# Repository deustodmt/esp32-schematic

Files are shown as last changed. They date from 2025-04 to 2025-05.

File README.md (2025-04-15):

# Proyecto PCB para Moto Eléctrica de Competición

Este repositorio documenta el diseño y desarrollo de una PCB para una moto eléctrica de competición. El objetivo principal es crear una placa personalizada basada en la ESP32-S3-DevKitC-1 que integre varios sensores y módulos esenciales para la recolección de datos, comunicación y navegación del vehículo.

---

## 📈 Estado actual del proyecto

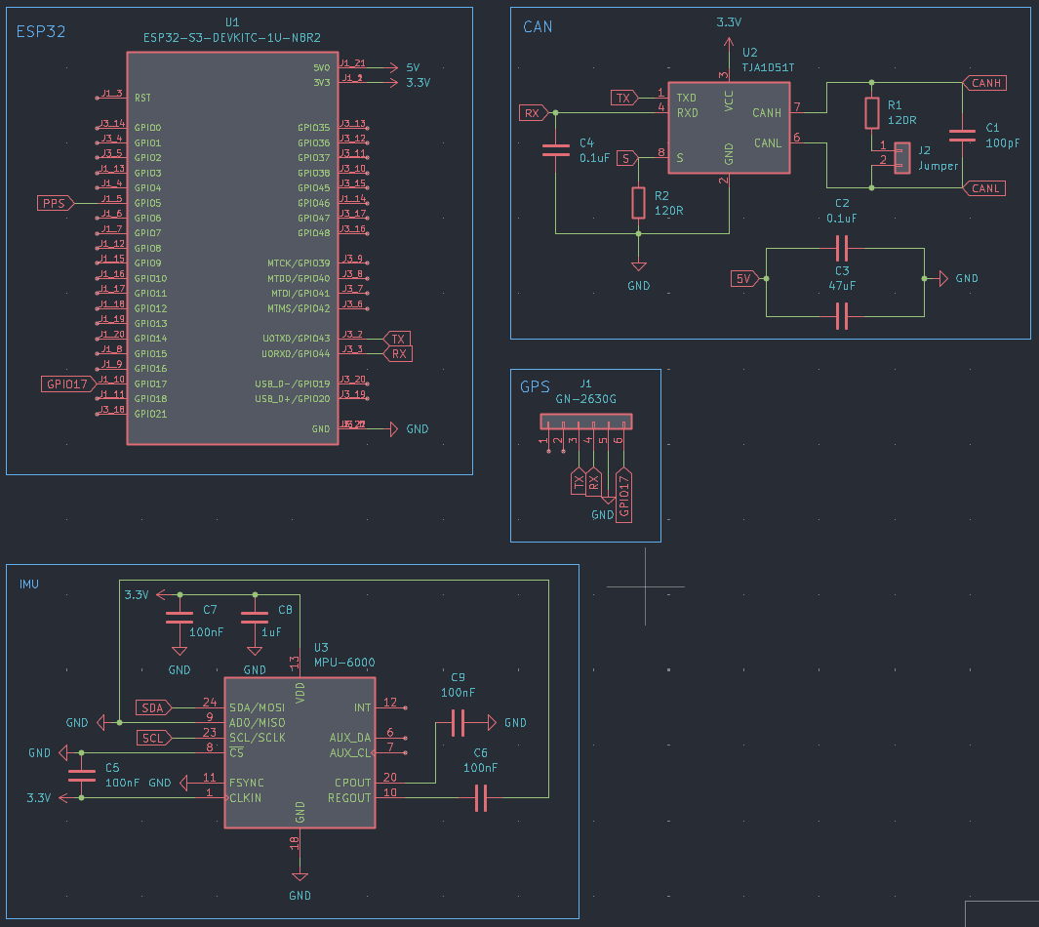
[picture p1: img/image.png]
schematic


---

## 🪤 Módulos incluidos en el diseño

### ESP32-S3-DevKitC-1
Microcontrolador principal encargado de recopilar datos de los sensores, procesarlos y transmitir información vía CAN o WiFi/Bluetooth. Este microcontrolador se elige por su versatilidad, potencia y conectividad.

### CAN (Controller Area Network)
Permite la comunicación robusta y rápida entre la ESP32 y otros controladores del sistema, como el BMS (Battery Management System) o la ECU (Electronic Control Unit). Se utiliza el transceptor TJA1051T para traducir las señales lógicas de la ESP32 al bus CAN.

### IMU (Unidad de Medición Inercial)
Usando el módulo MPU-6000, permite conocer la aceleración y rotación de la moto en tiempo real. Es fundamental para la telemetría y el análisis de dinámica del vehículo.

### GPS
El módulo GN-2630G proporciona la localización de la moto mediante señal satelital. Este dato es crucial para conocer la trayectoria y velocidad en pista.

### ENV (Sensor ambiental) *(Añadir cuando se incluya)*
Este módulo recogerá datos como temperatura, presión y humedad, los cuales podrían ser útiles para ajustar el rendimiento de la moto o estudiar las condiciones en pista.

---

## 📝 Diseño de la PCB

El diseño de la PCB ha sido elaborado buscando:
- **Minimizar interferencias** entre módulos sensibles como el GPS o la IMU.
- **Facilitar el ruteado** de las pistas, manteniendo las pistas de alimentación más anchas y las de señal bien definidas.
- **Disposición funcional** de los componentes, agrupando por función: comunicación, sensores, alimentación.
- **Posibilidad de depuración** y pruebas: se dejan pines de testeo accesibles.

Los principios seguidos incluyen buenas prácticas de colocación de condensadores de desacoplo, rutas cortas para señales críticas, y separación adecuada entre señales analógicas y digitales.

---

## ⚖️ Uso de KiCad

Para el diseño del proyecto se ha utilizado **KiCad**, una suite libre de diseño de PCB.

### Metodología de trabajo:
1. **Esquemático:** Creación del diagrama esquemático conectando todos los componentes.
2. **Asignación de huellas (footprints):** Asociación de cada componente con su huella física.
3. **Diseño de la PCB:** Colocación y ruteado de las pistas.
4. **Verificación DRC/ERC:** Comprobaciones de reglas eléctricas y de diseño.
5. **Exportación de archivos Gerber:** Preparación para fabricación.
6. **Renderizado 3D:** Visualización realista de la placa antes de su fabricación.

### Plugins útile:
- **KiCad-Diff:** Para ver cambios entre commits.
- **Interactive HTML BOM:** Genera una lista de materiales navegable visualmente.
- **SnapEDA / SamacSys Plugin:** Importación directa de modelos de componentes.

---

## 🚚 Fabricación de PCBs

Para la fabricación se recomienda:

- **JLCPCB**: https://jlcpcb.com/
  - Plataforma popular y asequible para fabricar placas PCB a partir de archivos Gerber.
- **LCSC**: https://lcsc.com/
  - Proveedor de componentes electrónicos que permite integración directa con JLCPCB para el montaje.
- **SnapMagic / SamacSys**: https://www.snapeda.com/
  - Herramienta para obtener símbolos, huellas y modelos 3D de componentes para integrarlos en KiCad.

---

## 📊 Conceptos básicos del diseño de PCBs

### Esquema de componentes (Schematic)
Representación lógica de cómo se conectan los componentes del circuito. No representa distancias ni posiciones físicas.

### Diseño de la PCB
Proceso de colocación física de los componentes y trazado de pistas que conectan los nodos definidos en el esquema.

### Renderizado 3D
Visualización tridimensional de la placa para comprobar posibles errores mecánicos y facilitar presentaciones.

### Archivos Gerber
Conjunto de archivos estándar que describen la geometría y capas de una placa PCB. Son enviados al fabricante para producir la placa.

---

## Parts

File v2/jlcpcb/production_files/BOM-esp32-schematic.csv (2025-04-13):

Comment | Designator | Footprint | LCSC | Quantity
TJA1051T | U2 | SOIC-8_3.9x4.9mm_P1.27mm |  | 1
GPS | J1 | PinHeader_1x06_P2.54mm_Vertical |  | 1
ESP32-S3-DEVKITC-1U-N8R2 | U1 | XCVR_ESP32-S3-DEVKITC-1U-N8R2 |  | 1
120R | R1 | R_1206_3216Metric |  | 1

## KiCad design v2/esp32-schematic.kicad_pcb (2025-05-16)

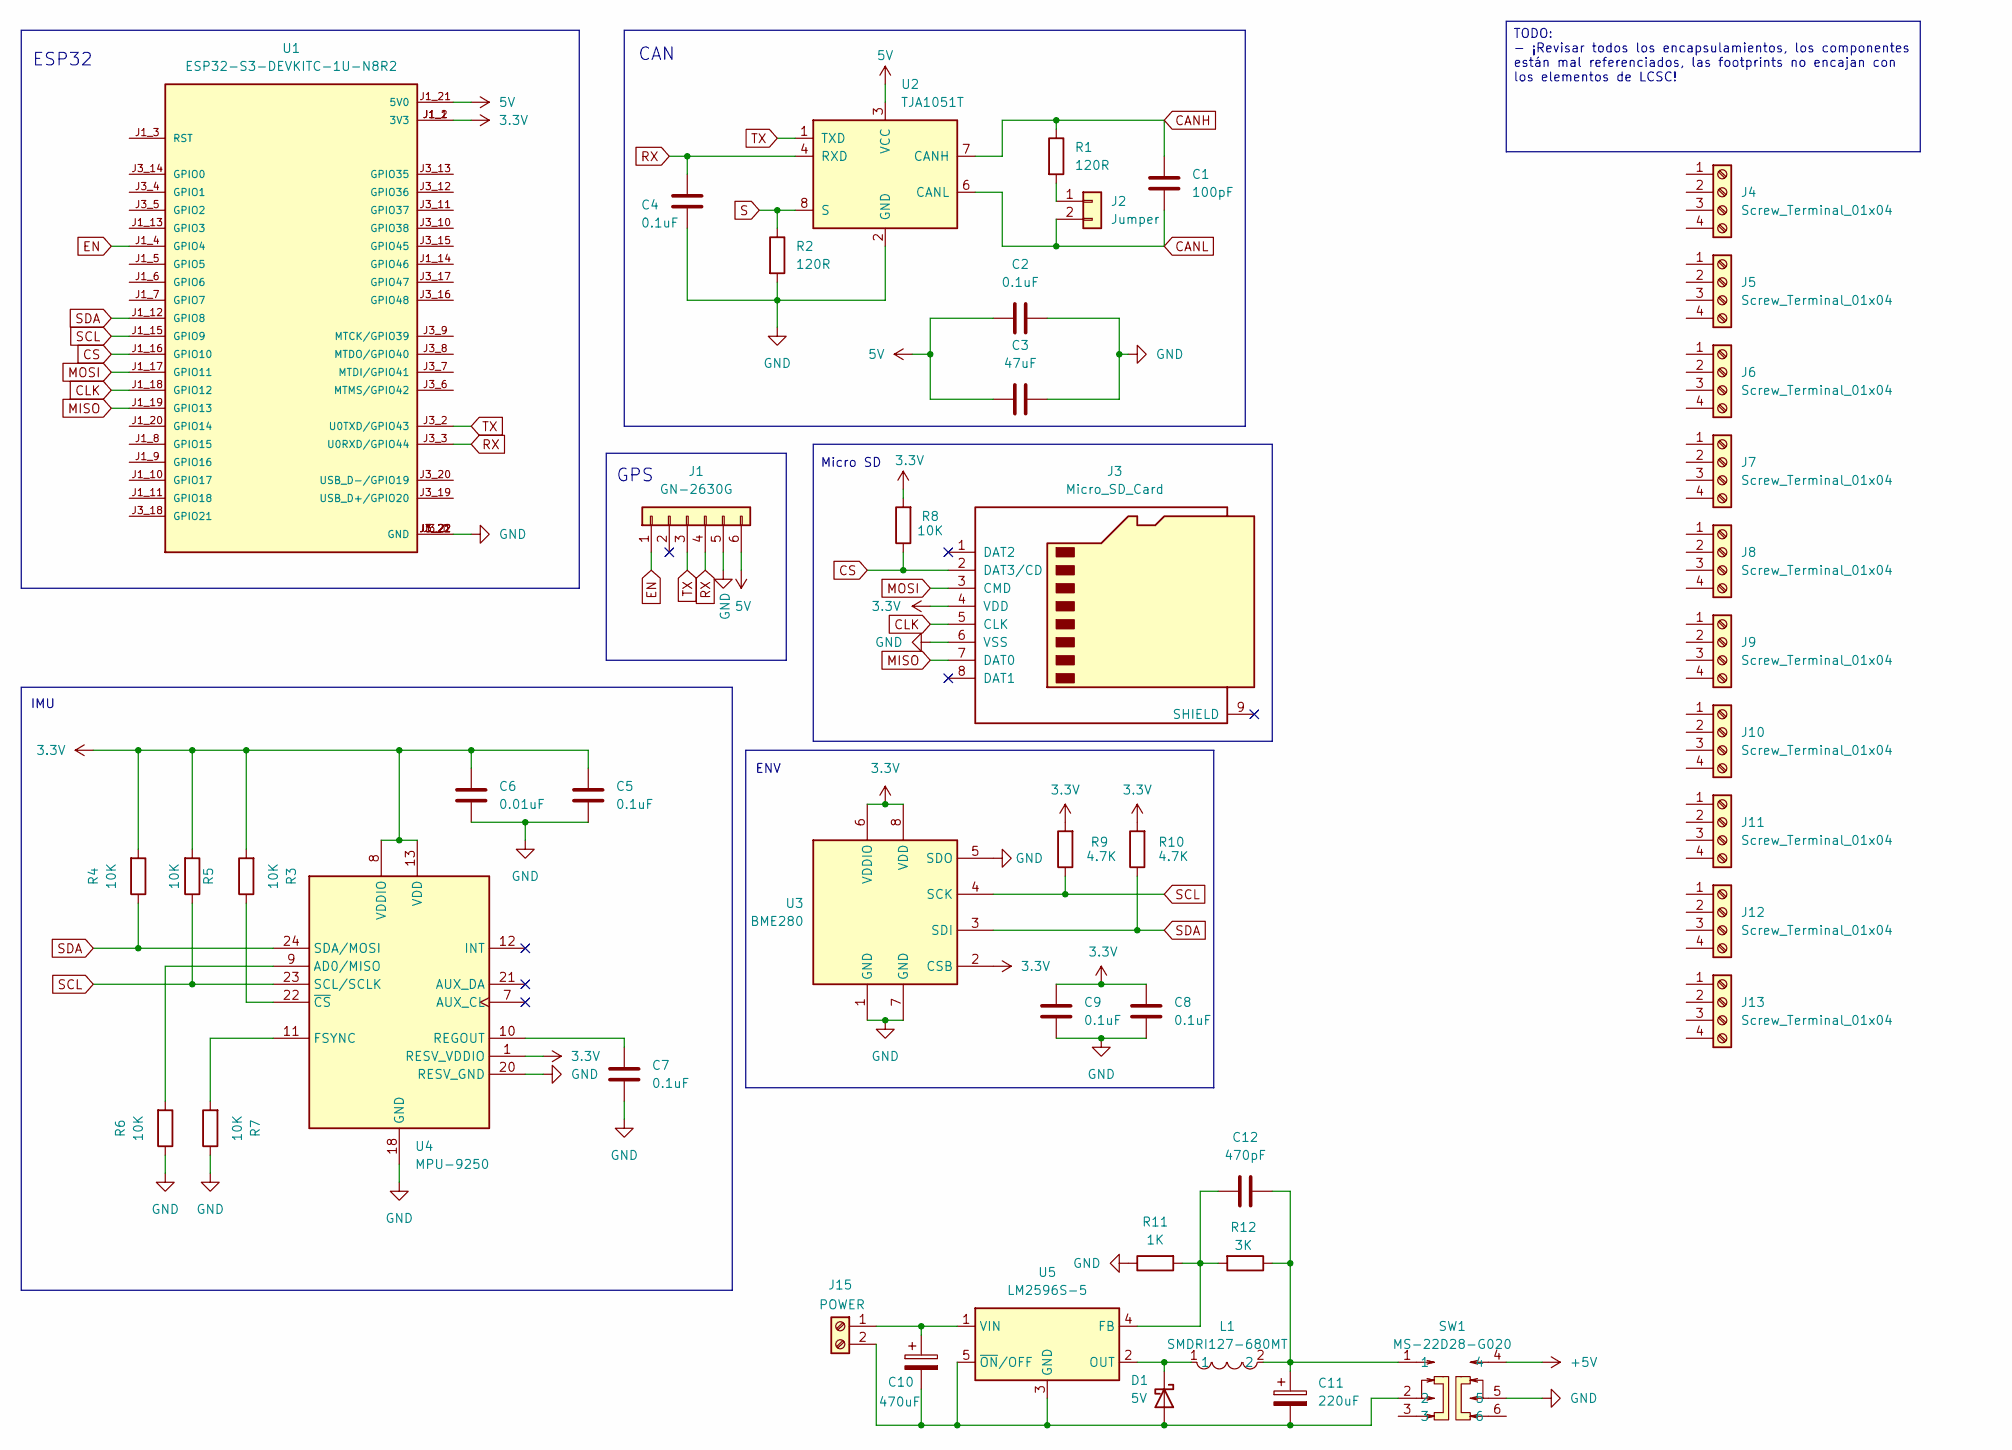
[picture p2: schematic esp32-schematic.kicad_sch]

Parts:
C1: 100pF; C_0805_2012Metric
C2, C4, C5, C7, C8, C9: 0.1uF; C_0805_2012Metric
C3: 47uF; C_0805_2012Metric
C6: 0.01uF; C_0805_2012Metric
C10: 470uF; CP_Radial_D10.0mm_P5.00mm
C11: 220uF; CP_Elec_10x10
C12: 470pF; C_0201_0603Metric
D1: 5V; D_SMA
J1: GN-2630G; PinHeader_1x06_P2.54mm_Vertical
J2: Jumper; PinHeader_1x02_P1.00mm_Vertical
J3: Micro_SD_Card; microSD_HC_Molex_104031-0811
J4, J5, J6, J7, J8, J9, J10, J11, J12, J13: Screw_Terminal_01x04; TerminalBlock_Phoenix_MKDS-1,5-4-5.08_1x04_P5.08mm_Horizont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
J15: POWER; TerminalBlock_Phoenix_PT-1,5-2-3.5-H_1x02_P3.50mm_Horizontal
L1: SMDRI127-680MT; IND-SMD_L12.3-W12.3_SMDRI127; LCSC Part C9907
R1, R2: 120R; R_1206_3216Metric
R3, R4, R5, R6, R7, R8: 10K; R_1206_3216Metric
R9, R10: 4.7K; R_1206_3216Metric
R11: 1K; R_0201_0603Metric
R12: 3K; R_Axial_DIN0411_L9.9mm_D3.6mm_P15.24mm_Horizontal
SW1: MS-22D28-G020; SW-SMD_MS-22D28-G020; LCSC Part C963205
U1: ESP32-S3-DEVKITC-1U-N8R2; XCVR_ESP32-S3-DEVKITC-1U-N8R2; PARTREV 5.3
U2: TJA1051T; SOIC-8_3.9x4.9mm_P1.27mm
U3: BME280; Bosch_LGA-8_2.5x2.5mm_P0.65mm_ClockwisePinNumbering
U4: MPU-9250; InvenSense_QFN-24_3x3mm_P0.4mm
U5: LM2596S-5; TO-263-5_TabPin3

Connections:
3.3V: C5.1, C6.1, C8.1, C9.1, J3.4 (VDD), R3.2, R4.2, R5.2, R8.2, R9.2, R10.2, U1.J1_1 (3V3), U1.J1_2 (3V3), U3.2 (CSB), U3.6 (VDDIO), U3.8 (VDD), U4.1 (RESV_VDDIO), U4.8 (VDDIO), U4.13 (VDD)
5V: C2.1, C3.1, J1.6, U1.J1_21 (5V0), U2.3 (VCC)
+5V: SW1.4
CANH: C1.1, R1.1, U2.7 (CANH)
CANL: C1.2, J2.2, U2.6 (CANL)
CLK: J3.5 (CLK), U1.J1_18 (GPIO12)
CS: J3.2 (DAT3/CD), R8.1, U1.J1_16 (GPIO10)
EN: J1.1, U1.J1_4 (GPIO4)
GND: C2.2, C3.2, C4.2, C5.2, C6.2, C7.2, C8.2, C9.2, J1.5, J3.6 (VSS), R2.2, R6.1, R7.1, R11.1, SW1.5, U1.J1_22 (GND), U1.J3_1 (GND), U1.J3_21 (GND), U1.J3_22 (GND), U2.2 (GND), U3.1 (GND), U3.5 (SDO), U3.7 (GND), U4.18 (GND), U4.20 (RESV_GND)
MISO: J3.7 (DAT0), U1.J1_19 (GPIO13)
MOSI: J3.3 (CMD), U1.J1_17 (GPIO11)
unnamed: C11.1, C12.2, L1.2, R12.1, SW1.1
unnamed: C10.2, C11.2, D1.2 (A), J15.2, SW1.2, U5.3 (GND), U5.5 (~ON/OFF)
unnamed: D1.1 (K), L1.1, U5.2 (OUT)
unnamed: J2.1, R1.2
unnamed: C10.1, J15.1, U5.1 (VIN)
unnamed: R6.2, U4.9 (AD0/MISO)
unnamed: R7.2, U4.11 (FSYNC)
unnamed: C7.1, U4.10 (REGOUT)
unnamed: R3.1, U4.22 (~CS)
unnamed: C12.1, R11.2, R12.2, U5.4 (FB)
RX: C4.1, J1.4, U1.J3_3 (U0RXD/GPIO44), U2.4 (RXD)
S: R2.1, U2.8 (S)
SCL: R5.1, R9.1, U1.J1_15 (GPIO9), U3.4 (SCK), U4.23 (SCL/SCLK)
SDA: R4.1, R10.1, U1.J1_12 (GPIO8), U3.3 (SDI), U4.24 (SDA/MOSI)
TX: J1.3, U1.J3_2 (U0TXD/GPIO43), U2.1 (TXD)

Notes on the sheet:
GPS
ESP32
CAN
Micro SD
IMU
ENV
TODO: - ¡Revisar todos los encapsulamientos, los componentes están mal referenciados, las footprints no encajan con los elementos de LCSC!

Board: 2 copper layers, 46 parts (0 on the bottom side), 25 nets, no tracks yet.

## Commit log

2025-04-13 GPS added and CAN in progress
    [BOM-esp32-schematic.csv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]
2025-04-13 CAN in progress
    [esp32-schematic.kicad_sch]
2025-04-14 CAN schematic and IMU schematic ready
    [esp32-schematic.kicad_pcb, esp32-schematic.kicad_sch]
2025-04-15 Readme Updated
    [esp32-schematic.kicad_sch]
2025-04-26 Micro SD added, IMU is now the MPU-9250, connections were moved in the ESP32 pins and the right footprints were added
    [esp32-schematic.kicad_pcb, esp32-schematic.kicad_sch]
2025-04-29 SD slot added, ENV added, issues fixed
    [esp32-schematic.kicad_pcb, esp32-schematic.kicad_sch]
2025-04-29 missing footprints added
    [esp32-schematic.kicad_pcb]
2025-05-11 DC-DC added, and bornes for the esp32 in progress
    [esp32-schematic.kicad_pcb, esp32-schematic.kicad_sch]
2025-05-16 Reorganisation of the project, the v1 will be the test prototype and the v2 will be implementing the devices on the board directly. Also the libraries have been reorganised, each version will share a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
    [BOM-esp32-schematic.csv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]
2025-05-17 external power supply entry added, and todo list updated
    [esp32-schematic.kicad_pcb, esp32-schematic.kicad_sch]
2025-08-06 index file added to identify the footprints of the components easily with a legible name
